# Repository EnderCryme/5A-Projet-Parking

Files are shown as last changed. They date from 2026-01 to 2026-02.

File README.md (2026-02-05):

# 🏆 PSM - Modular Smart Parking System
### *Winner of "Most Technical Project" - Digital Majors Competition 2025*




<div align="center">
  PSM Prototype
  <p><em>Our award-winning prototype at the competition</em></p>
</div>

---
## 🏅 **Award & Recognition**
We are proud to announce that **PSM won the "Most Technical Project" award** at Digital Majors Competition 2025 !
Our solution stood out for its:
* ✅ **Distributed IoT architecture** combining FPGA, STM32, and BeagleY-AI
* ✅ **Custom RISC-V SoC** implemented on FPGA
* ✅ **Real-time ANPR system** with OpenCV + Tesseract
* ✅ **Industrial-grade implementation** with Zephyr RTOS

<div align="center">
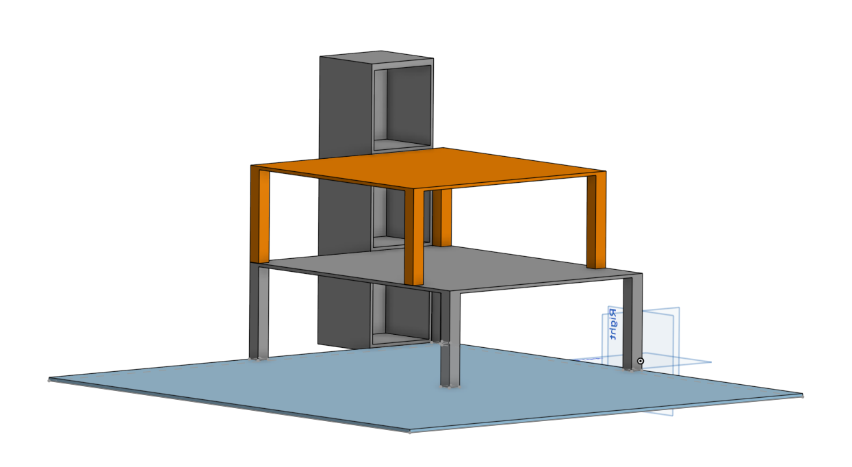
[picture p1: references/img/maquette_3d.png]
3D Model
  
  <p><em>3D model of our mechanical design</em></p>
</div>

---

## 🌍 **Choose Your Language**
For full project details, please select your preferred language:

🇫🇷 **[Version Française (README_fr.md)](README_FR.md)**
🇬🇧 **[English Version (README_en.md)](README_EN.md)**

---

## 🔧 **Quick Overview**
**Key Features:**
- **AI-powered ANPR** (Automatic Number Plate Recognition)
- **Distributed MQTT network** with BeagleY-AI as central broker
- **Custom RISC-V SoC** on FPGA for motor control
- **Zephyr RTOS** for real-time RFID processing
- **Modular design** with 3D-printed mechanical components

**Tech Stack:**





---

## 👥 **Project Team**
* **FALDA Andy**
* **CAUQUIL Vincent**
* **ES-SRIEJ Youness**
* **CLERVILLE Annabelle**

---

## 📸 **Gallery**
<div align="center">
  <table>
    <tr>
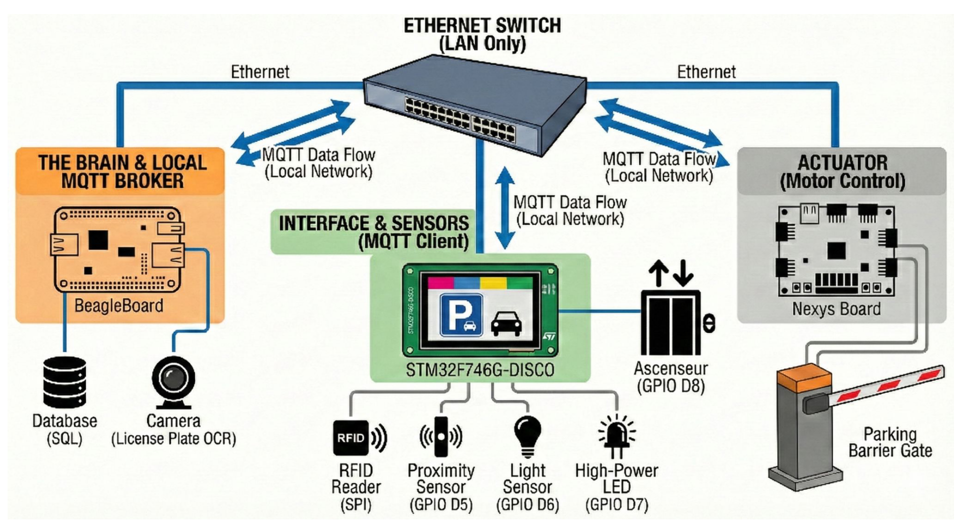
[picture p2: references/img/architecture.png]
      <td></td>
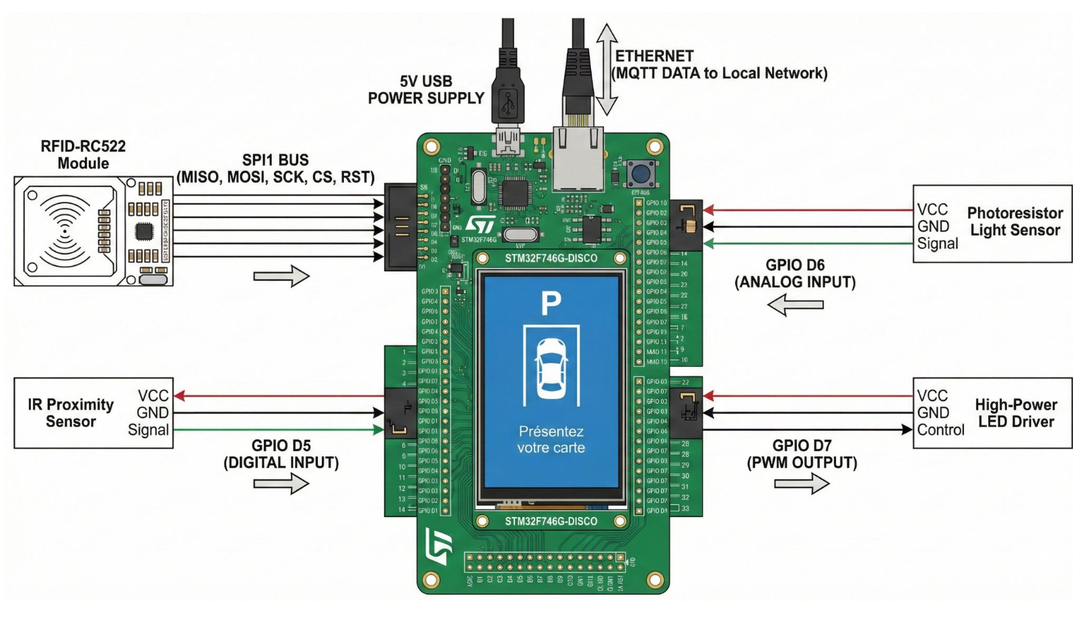
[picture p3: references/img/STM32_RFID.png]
      <td></td>
    </tr>
    <tr>
      <td align="center"><em>Complete system</em></td>
      <td align="center"><em>RFID entry module</em></td>
    </tr>
  </table>
</div>

> *Note: For more images and technical diagrams, please refer to the full documentation in [README_fr.md](README_FR.md) or [README_en.md](README_EN.md).*

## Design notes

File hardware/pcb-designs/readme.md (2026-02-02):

# **PCB Design**





Ce répertoire contient l’ensemble des **cartes électroniques (PCB)** développées pour le système.  
Tous les schémas et routages ont été réalisés sous **KiCad 7**, en respectant les contraintes des signaux rapides (MIPI, USB), la sécurité électrique, ainsi que la compatibilité avec **USB‑C Power Delivery**.

---
# 📁 Structure du Répertoire

```
/pcb-designs
   ├── adaptateur-24pin/            # Convertisseur Mipi to CSI
   │   ├── GERBER-Adaptateur/
   │   ├── Adapat_24pin_22pin.kicad_pcb
   │   ├── Adapat_24pin_22pin.kicad_sch
   │   └── Adapat_24pin_22pin.rar
   ├── bms/                            # Layout et ressources de design du BMS
   │   ├── calculations/               # Justifications techniques
   │   │   ├── load_estimation.csv
   │   │   └── pack_4S3P_energy.csv
   │   ├── designs/                    # Sources du projet KiCad
   │   │   ├── BMS.csv                 # BOM compatible JLCPCB
   │   │   ├── BMS_schem.kicad_prl     # Fichier projet KiCad du BMS
   │   │   ├── BMS_schem.kicad_sch     # Schématique complet
   │   │   ├── BMS_pcb.kicad_pcb       # Routage (4 couches, impédance contrôlée)
   │   │   ├── BMS.pdf                 # Feuilles circuits au format pdf ⚠ Ne pas imprimer comme tel,
   │   │   └── ....                      il y'a des feuilles inutiles utilisés pour simplifié le circuitage
   │   ├── references/                 # Datasheets composants (STM32, STUSB...)
   │   ├── test-EVM/                   # Tests sur carte d'évaluation (BQ40Z50)
   │   ├── BMS_schem.png
   │   ├── bilan-puissance-max.png
   │   ├── readme.md
   │   └── .... ⚠ le firmware RP2350 est trouvable au : /software/sw-fw-BMS
   ├── common-libs/                    # Lib cstm avec les empreintes steps et schémas utilisés
   └── detection-lumiere/              # Détection d'intensité lumineuse
       ├── Gerber/
       ├── Lumiere.kicad_pcb
       ├── Lumiere.kicad_sch
       └── readme.md         
```

---

## **1. BMS – Battery Management System**

Dans le cadre du projet, il m’a été confié de gérer **toute la partie puissance**, ainsi que d’anticiper différents **scénarios hors‑réseau**, impliquant l’utilisation d’un système de batteries rechargeable.

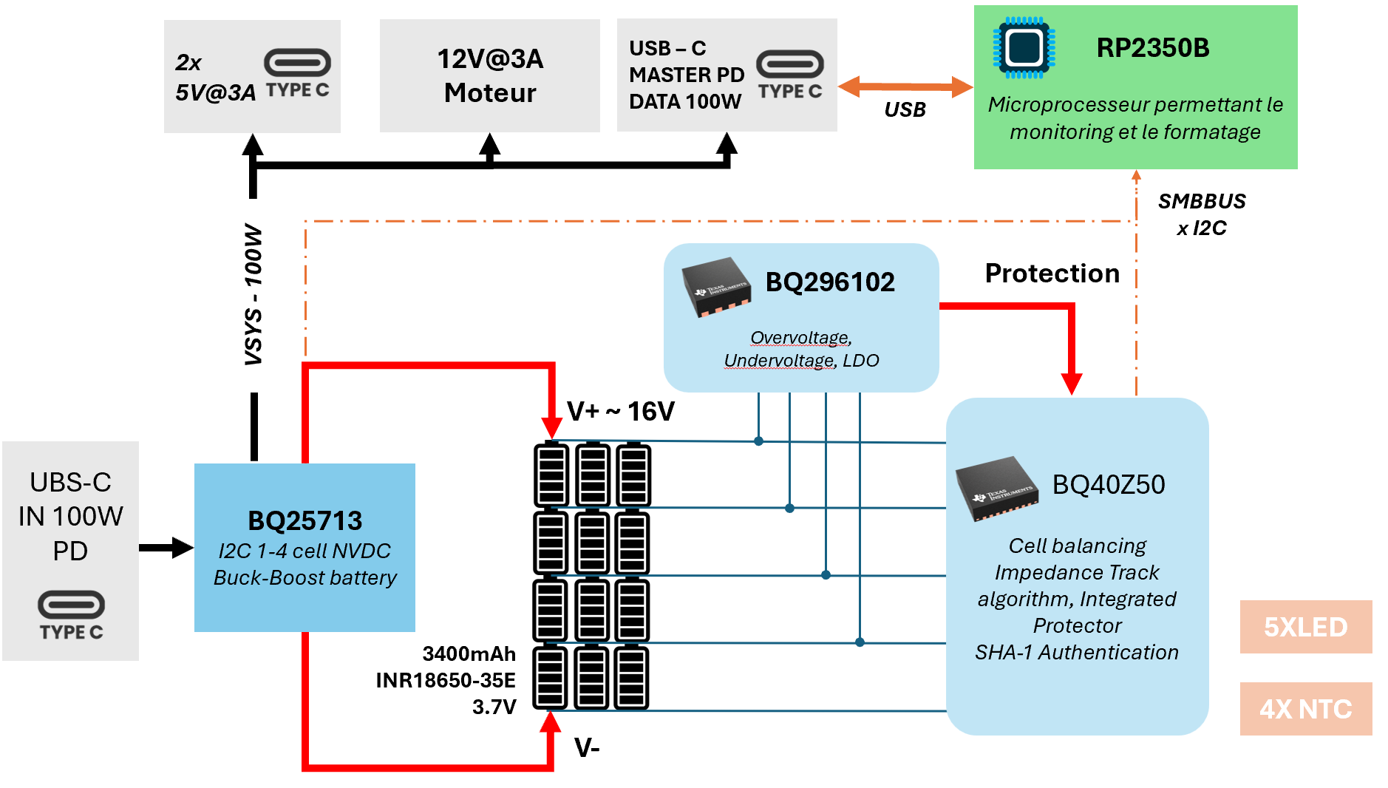
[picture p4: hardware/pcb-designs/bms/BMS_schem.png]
BMS


L’alimentation principale repose sur un port **USB Type‑C avec Power Delivery (PD)** pour plusieurs raisons :

### **Pourquoi l’USB Type‑C PD ?**
- **Standard universel** : compatible avec la majorité des chargeurs actuels.  
- **Négociation automatique de puissance (PD)** :  
  Le système consomme précisément ce dont il a besoin, et limite ce qu’il fournit.  
- **Flexibilité du système** :  
  Permet d’adapter le nombre de cellules, l’autonomie et le chargeur utilisé.  
  Plage de puissance supportée : **5 W → 100 W**.

Le système sélectionne automatiquement la tension adéquate parmi les différents PDO du chargeur (5V / 9V / 12V / 15V / 20V).  
Cela le rend particulièrement robuste pour des scénarios variés : installations autonomes, postes IoT isolés, alimentation redondante, robotique mobile, etc.

---

## **2. Capteur de lumière**

L’intégration d’un **capteur de luminosité** permet de détecter un niveau d’éclairage insuffisant pour activer automatiquement l’éclairage du site.

### Objectif
- Allumer les LED dès qu’il fait suffisamment sombre (ex. crépuscule).  
- Éviter tout éclairage inutile en pleine journée.

### Couplage avec un capteur de présence
Associé à un détecteur de mouvement, ce capteur permet :
- Une **réduction de la consommation électrique**.  
- Une **diminution de la pollution lumineuse** pour le voisinage.  
- Une **optimisation énergétique** en n’éclairant que lorsque cela est nécessaire.

Cette approche rend le système plus intelligent, écoresponsable et parfaitement adapté à une installation extérieure automatique.

---

## **3. Adaptateur MIPI/CSI 24‑pin vers 22‑pin**

Cette carte d’adaptation permet de rendre compatible une caméra industrielle **Sony [IMX415](https://www.aliexpress.com/p/tesla-landing/index.html?productId=1005006459824998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)** (connecteur **24‑pins**) avec nos plateformes **BeagleBone AI‑64 / BeagleBone Y‑AI**, qui utilisent un connecteur **22‑pins CSI‑2**.

### Pourquoi un adaptateur ?
- Les caméras industrielles IMX utilisent fréquemment un **pinout 24‑pins propriétaire**.  
- Les cartes BBY reposent sur un **pinout 22‑pins CSI‑2 standardisé**.  
- Une réaffectation correcte des signaux MIPI est nécessaire :  
  - Clock lanes  
  - Data lanes  
  - Alimentation  
  - I²C / Reset / Standby  

### Rôle de la carte
- Conversion **mécanique** entre les connecteurs 24→22.  
- Conversion **électrique passive**, sans électronique active.  
- **Maintien de l’intégrité des signaux haute‑vitesse** grâce à :  
  - une impédance contrôlée,  
  - des longueurs adaptées,  
  - un routage équilibré des paires différentielles.

Cette carte garantit une compatibilité propre et robuste avec notre matériel, tout en conservant les performances du capteur IMX415.

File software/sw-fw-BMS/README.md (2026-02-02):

# Firmware/Software BMS Intelligent 

Cette section contient le firmware de contrôle pour le sous-ensemble BMS. Développé en **MicroPython**, ce logiciel transforme le RP2350 en une unité de gestion intelligente capable de dialoguer avec le contrôleur **BQ40Z50** via le protocole **SMBus**.

Le code assure la lecture des paramètres critiques de la batterie, la gestion de l'affichage local et le pilotage des sécurités de l'étage de puissance.

## 🛠️ Architecture du Firmware/Software

### 1. Communication SMBus / I2C

Le firmware exploite le bus I2C (GPIO 8 & 9) à une fréquence de 400kHz pour interroger les registres standards du BQ40Z50:

* **V Tension (`0x09`)** : Acquisition en millivolts.
* **A Courant (`0x0A`)** : Lecture signée gérant la charge (+) et la décharge (-).
* **% État de Charge (`0x0D`)** : Récupération directe du SoC (State of Charge).
* **T Température (`0x08`)** : Conversion de Kelvin (0.1°K) vers Celsius.

### 2. Logique de Contrôle & Sécurité

Le firmware agit comme le superviseur du système via des signaux de contrôle dédiés :

* **Signal CTRL (`GPIO 44`)** : Pilotage de la grille du MOSFET DMP3035 pour l'activation des sorties USB-C 5V@3A.
* **Monitoring ADC (`GPIO 43`)** : Surveillance de la tension VBUS via un pont diviseur de tension (47k/33k) pour valider la régulation.

## 🚀 Installation & Autorun

### 1. Préparation du RP2350

* Téléchargez le firmware MicroPython `.uf2` pour **Pico 2** sur [micropython.org](https://micropython.org/download/RPI_PICO2/).
* Maintenez le bouton **SW2** (USB_BOOT) enfoncé et branchez le module en USB.
* Copiez le fichier `.uf2` dans le lecteur `RPI-RP3`.

### 2. Déploiement du Code

Utilisez **Thonny IDE** pour téléverser les fichiers à la racine du microcontrôleur :
*  `ssd1306.py` : Pilote basse couche pour l'écran OLED.
* **`main.py`** : Script principal contenant la boucle de monitoring (se lance automatiquement à l'allumage).

## 📡 Interface Utilisateur (OLED)

L'affichage est rafraîchi toutes les secondes et présente un dashboard complet:

* **Ligne 1** : Tension (V) et Température (°C).
* **Ligne 2** : Courant de charge/décharge (A).
* **Ligne 3** : Barre de progression graphique du niveau de batterie.

## 📂 Structure des fichiers Software
```text
sw-fw-BMS/
 ├── BMS_schem.png    # Schéma récapitulatif de l'architecture du BMS
 ├── README.md
 ├── main.py          # Logique métier et boucle principale.
 └── ssd1306.py       # Bibliothèque d'affichage I2C.
```

---

### 📑 Table des Commandes I2C (SMBus/Relier aux registres visibles sur le BQstudio)

| Commande | Registre (Hex) | Unité | Description |
| --- | --- | --- | --- |
| **Temperature** | `0x08` | 0.1°K | Température interne du pack (convertie en °C dans le code).
| **Voltage** | `0x09` | mV | Tension totale aux bornes du pack batterie.
| **Current** | `0x0A` | mA | Courant instantané (positif = charge, négatif = décharge).
| **RelativeSoC** | `0x0D` | % | État de charge restant par rapport à la capacité actuelle.

---

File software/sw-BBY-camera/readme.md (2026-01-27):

# Système de Gestion Centralisé (BeagleBone Node)







## 📖 Description du Projet

Ce dépôt contient le "cerveau" du système de parking intelligent. Exécuté sur une **BeagleBone Black / BeagleY-AI**, ce nœud centralise la logique métier, la gestion de la base de données et le traitement d'images.

Il agit comme une passerelle (Gateway) qui coordonne les périphériques via MQTT (comme le nœud STM32), offre une interface Web d'administration et effectue la reconnaissance optique de caractères (ALPR) en temps réel.

### Fonctionnalités Clés

* **Reconnaissance LAPI (ALPR) :** Détection et lecture automatique des plaques d'immatriculation via **OpenCV** (Haar Cascades) et **Tesseract OCR**.
* **Serveur Web (Flask) :** Dashboard complet pour l'administration (IT) et les clients (User) avec streaming vidéo MJPEG.
* **Base de Données (SQLite) :** Gestion persistance des utilisateurs, historique des entrées/sorties et droits d'accès.
* **Logique de Contrôle :** Moteur de décision fusionnant les données RFID (MQTT) et Vidéo pour piloter les barrières.
* **Affichage Local (SPI) :** Pilotage d'une matrice LED/LCD pour les messages d'accueil et la météo locale.
* **Mode Hybride :** Capacité de fonctionner en mode "Simulation" sur PC (Windows) ou en mode "Matériel Réel" sur Linux (détection automatique).

## 🛠 Architecture Matérielle

* **SBC :** BeagleBone Black Wireless / BeagleY-AI (Debian Linux)
* **Vision :** Webcams USB (Entrée/Sortie)
* **Affichage :** Matrice LED (MAX7219) via SPI
* **Capteurs :** BME680 (Température/Pression/Humidité)

### Pinout & Connexions

| Périphérique | Pin BeagleBone | Bus | Description |
| :--- | :--- | :--- | :--- |
| **LCD / Matrice** | `P9_17` (CS0) | SPI0 | Affichage messages défilants |
| **Capteur BME680** | `P9_28` (CS1) | SPI0 | Télémétrie environnementale |
| **Caméra Entrée** | USB Host | USB | Flux Vidéo 1 (`/vid_in`) |
| **Caméra Sortie** | USB Host | USB | Flux Vidéo 2 (`/vid_out`) |

## 📡 API MQTT

Le serveur agit comme le maître logique sur le réseau local.

| Topic | Direction | Payload | Description |
| :--- | :--- | :--- | :--- |
| `RFID/ID` | Sub (In) | `[UID]` | Réception d'un badge scanné par le STM32. |
| `RFID/CMD` | Pub (Out) | `UNLOCK_READY` | Indique au STM32 que le badge est valide. |
| `RFID/CMD` | Pub (Out) | `DENY` | Indique au STM32 que l'accès est refusé. |
| `parking/barrier_x/state` | Pub (Out) | `OPEN` / `CLOSE` | Ordre d'ouverture des barrières physiques. |
| `RFID/ADD` | Sub (In) | `[UID]` | Demande d'ajout rapide d'un badge (Admin). |

## ☁️ Ouverture : Architecture Cloud & Edge Computing

Actuellement, le projet fonctionne en mode "autonome" (le serveur Web et l'IA tournent sur la même machine). Pour un déploiement réel à grande échelle (ex: via Render ou AWS), l'architecture évoluerait vers un modèle **IoT Edge** :

1. **Sur site (Edge Node)** : Un script python léger (`local_bridge.py`) tourne sur la BeagleBone. Il gère :
    * L'acquisition vidéo et l'OCR (Traitement local pour rapidité).
    * Le pilotage physique (GPIO) des barrières et écrans LCD.
    * La communication sécurisée via **MQTT (TLS)** vers le Cloud.

2. **Sur le Cloud (Server Node)** : L'application Flask (`main_v08d.py`) est hébergée sur un serveur distant. Elle gère :
    * La base de données centralisée.
    * L'interface administrateur accessible de partout.
    * La validation des entrées : elle reçoit la plaque via MQTT, vérifie les droits, et renvoie l'ordre d'ouverture à la BeagleBone.

3. **Flux Vidéo** : Plutôt que de streamer de la vidéo lourde, le nœud local envoie des **Snapshots (images instantanées)** en base64 via MQTT ou via un tunnel WebRTC lors des événements importants (détection, effraction), optimisant ainsi la bande passante 4G/5G des parkings isolés.

## ⚙️ Installation & Démarrage

Le projet nécessite Python 3.9+ et les drivers système.

### Pré-requis

```bash
# Installation des dépendances système (Debian/Ubuntu)
sudo apt update
sudo apt install python3-opencv tesseract-ocr libopenjp2-7

# Installation des bibliothèques Python
pip install -r requirements.txt

```

### Lancement

Le système détecte automatiquement s'il tourne sur un PC (Simulation) ou sur la BeagleBone (SPI activé).

```bash
# Lancement du serveur principal
python3 main_v08d.py

```

*L'interface web est accessible sur `http://<IP_BEAGLEBONE>:5000*`

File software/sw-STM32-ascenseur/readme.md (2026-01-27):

# Système de Contrôle d'Ascenseur Intelligent (STM32 Node)






## 📖 Description du Projet

Ce dépôt contient le firmware d'un système de contrôle d'ascenseur de précision. Le projet implémente un pilotage avancé de moteur pas-à-pas associé à un asservissement par capteur de distance laser pour garantir un positionnement exact aux différents niveaux.

Le système intègre une gestion complète de la sécurité (fin de course, arrêts d'urgence) et une rampe d'accélération logicielle pour assurer des mouvements fluides et prévenir l'usure mécanique.

### 🚀 Fonctionnalités Clés

* **Pilotage TMC5160 (SPI) :** Gestion avancée du driver moteur avec surveillance d'état et résilience automatique en cas de défaut.
* **Recalibrage Automatique :** Séquence d'initialisation au démarrage pour définir le point zéro via capteur de fin de course.
* **Positionnement Laser (ToF) :** Utilisation du capteur VL53L0X pour le recalage en temps réel et la correction de dérive.
* **Rampe d'Accélération :** Algorithme de vitesse dynamique pour limiter les secousses lors des phases de départ et d'arrêt.
* **Gestion Multi-étages :** Support natif de 3 niveaux configurables avec système de mémorisation des appels en attente.
* **Sécurité Active :** Surveillance du bouton d'arrêt d'urgence et détection de collision/sol lors de la descente.

## 🛠 Architecture Matérielle

* **MCU :** STM32F746NG (Arm Cortex-M7)
* **Board :** STM32F746G-DISCO
* **Driver Moteur :** TMC5160 SilentStepStick
* **Capteur :** VL53L0X (Laser Distance)

### Pinout & Connexions (Overlay)

| Périphérique | Pin STM32 | Type | Description |
| :--- | :--- | :--- | :--- |
| **Moteur STEP** | `PA15` | GPIO Out | Signal de pas |
| **Moteur DIR** | `PI2` | GPIO Out | Direction du mouvement |
| **Moteur ENABLE**| `PI3` | GPIO Out | Activation driver (Actif Low) |
| **TMC CS** | `PA8` | GPIO Out | Chip Select SPI |
| **Fin de Course** | `PH6` | GPIO In | Capteur Point Zéro (D6) |
| **Appel Étage 0**| `PG6` | GPIO In | Bouton Rez-de-chaussée (D2) |
| **Appel Étage 1**| `PG7` | GPIO In | Bouton Niveau 1 (D4) |
| **Appel Étage 2**| `PI0` | GPIO In | Bouton Niveau 2 (D5) |

## ⚙️ Paramètres de Calibration (main.c)

| Paramètre | Valeur | Unité |
| :--- | :--- | :--- |
| **Hauteur Étage 0** | 0 | mm |
| **Hauteur Étage 1** | 170 | mm |
| **Hauteur Étage 2** | 336 | mm |
| **Résolution** | 350 | pas / mm |
| **Tolérance** | 10 | mm |

## 📡 Configuration & Build

Le projet est basé sur **Zephyr RTOS**.

### Pré-requis
* Zephyr SDK installé.
* West build tool.

### Commandes

```bash
# Compiler le projet pour la STM32F746G-DISCO
west build -p -b stm32f746g_disco

# Flasher la carte
west flashn --runner openocd

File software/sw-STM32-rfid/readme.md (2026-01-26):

# Système d'Accès Parking Automatisé (STM32 Node)






## 📖 Description du Projet

Ce dépôt contient le firmware du sous-système d'interface et de gestion d'accès pour un parking automatisé. Le système repose sur une architecture IoT distribuée où ce module STM32 agit comme un **nœud de périphérie (Edge Node)** intelligent.

Il assure l'interface homme-machine, l'acquisition des données environnementales en temps réel et la sécurité physique de l'accès (Anti-Tailgating) avant de communiquer avec le serveur central (BeagleBoard) via MQTT sur Ethernet.

### 🚀 Fonctionnalités Clés

* **Identification RFID (SPI) :** Lecture de badges Mifare via module RC522.
* **Interface Tactile (LVGL) :** IHM interactive avec rotation logicielle (180°) pour adaptation mécanique.
* **Gestion Éclairage (GPIO) :** Pilotage automatique via capteur de luminosité et relais de puissance.
* **Sécurité Active :** Algorithme "Anti-Tailgating" pour prévenir la fraude au passage barrière.
* **Mode Maintenance :** Badge Administrateur (`UID: AA63F605`) pour gestion locale (Ajout/Suppr clients).
* **Communication IoT :** Client MQTT asynchrone pour la télémétrie et le contrôle distant.

## 🛠 Architecture Matérielle

* **MCU :** STM32F746NG (Arm Cortex-M7)
* **Board :** STM32F746G-DISCO
* **Affichage :** LCD 4.3" (480x272) capacitif
* **Réseau :** Ethernet (RJ45)

### Pinout & Connexions (Overlay)

| Périphérique | Pin STM32 | Type | Description |
| :--- | :--- | :--- | :--- |
| **RFID RC522** | SPI2 Bus | SPI | Lecteur de badges 13.56MHz |
| **RFID CS** | `PA8` | GPIO Out | Chip Select RFID |
| **Capteur Prox** | `PI0` | GPIO In | Détection présence véhicule (Actif High) |
| **Capteur Lum** | `PH6` | GPIO In | Photorésistance (Actif Low) |
| **Relais LED** | `PI3` | GPIO Out | Commande éclairage puissance 12V |
| **Backlight** | `PK3` | GPIO Out | Rétroéclairage LCD (Eco-mode) |

## 📡 API MQTT

Le système communique sur le réseau local configuré tel que :
Broker @ 192.168.78.2, STM32 @ 192.168.78.3

| Topic | Direction | Payload | Description |
| :--- | :--- | :--- | :--- |
| `RFID/ID` | Pub (Out) | `[UID]` | Envoi de l'UID scanné au serveur. |
| `RFID/PRESENCE` | Pub (Out) | `0` / `1` | État du capteur de présence véhicule. |
| `RFID/CMD` | Sub (In) | `UNLOCK`/`DENY` | Réponse du serveur (Accès autorisé/refusé). |
| `parking/barrier_0/state` | Pub/Sub | `OPEN`/`CLOSE` | Commande directe de la barrière physique. |

## ⚙️ Configuration & Build

Le projet est basé sur **Zephyr OS**.

### Pré-requis
* Zephyr SDK installé.
* West build tool.

### Commandes de Build

```bash
# Compilation propre pour la cible disco
west build -p always -b stm32f746g_disco

# Flashage sur la carte
west flash

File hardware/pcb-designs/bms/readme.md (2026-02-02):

# **Battery Management System (BMS)**






Ce dossier contient l’ensemble des fichiers de conception de la **carte BMS** (Battery Management System).  
L'objectif est de fournir une alimentation autonome, robuste et sécurisée pour le système embarqué hétérogène (BeagleY-AI, STM32, FPGA Nexys et moteurs).

Tout est conçu sous **KiCad 7**, avec une attention particulière aux contraintes haute tension (16.8 V), aux courants forts et à la sécurité thermique.

---

# 📁 Structure du Répertoire

```
bms/                               # Layout et ressources de design du BMS
   ├── calculations/               # Justifications techniques
   │   ├── load_estimation.csv
   │   └── pack_4S3P_energy.csv
   ├── designs/                    # Sources du projet KiCad
   │   ├── BMS.csv                 # BOM compatible JLCPCB
   │   ├── BMS_schem.kicad_prl     # Fichier projet KiCad du BMS
   │   ├── BMS_schem.kicad_sch     # Schématique complet
   │   ├── BMS_pcb.kicad_pcb       # Routage (4 couches, impédance contrôlée)
   │   ├── BMS.pdf                 # Feuilles circuits au format pdf ⚠ Ne pas imprimer comme tel,
   │   └── ....                      il y'a des feuilles inutiles utilisés pour simplifié le circuitage
   ├── references/                 # Datasheets composants (STM32, STUSB...)
   ├── test-EVM/                   # Tests sur carte d'évaluation (BQ40Z50)
   ├── BMS_schem.png
   ├── bilan-puissance-max.png
   ├── readme.md
   └── .... ⚠ le firmware RP2350 est trouvable au : /software/sw-fw-BMS
```

---

## **1. Architecture Système**

Le BMS ne se contente pas de charger des batteries ; il gère toute la distribution de puissance. L'architecture repose sur un trio de composants **Texas Instruments** pour la partie puissance/sécurité, et un **RP2350** pour l'intelligence applicative.

Architecture Simplifiée

### **Le Trio de Puissance (TI)**
La mesure critique et la sécurité sont **100 % hardware**, découplées du microcontrôleur pour une fiabilité maximale.

| Composant | Fonction | Pourquoi ce choix ? |
|:---|:---|:---|
| **BQ25713** | Chargeur Buck-Boost NVDC | Gère l'USB-C PD (5V→20V) et charge le pack quelle que soit l'entrée. |
| **BQ40Z50** | Fuel Gauge & Protection | Algorithme *Impedance Track™*, balancing cellules, protections primaires. |
| **BQ296102** | Protection Secondaire | Fusible électronique ultime (OVP/UVP) totalement indépendant. |

> **Note importante :** La configuration bas niveau du BQ40Z50 (profils batterie `.gg`, calibration) nécessite l'outil **TI EV2400**. Sans cela, la puce reste en mode défaut.

---

## **2. Dimensionnement du Battery Pack – 4S3P**

Le choix des cellules s'est porté sur des **Samsung INR18650‑35E** (3.7 V, 3400 mAh), assemblées en une configuration **4S3P**.

### **Caractéristiques du Pack**
*   **Capacité :** $3 \times 3.4\,Ah = 10.2\,Ah$
*   **Énergie :** $14.8\,V \times 10.2\,Ah = 151\,Wh$
*   **Tension Nominale :** 14.8 V
*   **Tension Max (Charge) :** 16.8 V
*   **Tension Min (Sécurité) :** 12.8 V

### **2.1. Justification du 4S et Évolution vers 20 V**

**L'approche initiale :**
Le pack 4S a été dimensionné initialement pour s'aligner sur une tension système globale de **12 V à 15 V**, idéale pour limiter les pertes de conversion vers les rails logiques (5V) et périphériques standards (12V).

**Le constat mécanique :**
Lors des tests d'intégration, nous avons remarqué que le moteur pas-à-pas de l'ascenseur (Stepper) manquait de fluidité sous 15 V (à-coups à haute vitesse, couple instable). Les essais ont montré un comportement mécanique optimal et parfaitement fluide sous **18–20 V**.

**La solution architecturale (Buck-Boost) :**
Ce changement de prérequis n'a pas impacté la batterie. L'architecture de puissance de la carte BMS intègre une topologie flexible :
*   **Buck (Abaisseur) :** Pour générer les rails 12 V, 5 V et 3.3 V avec un haut rendement.
*   **Boost (Élévateur) :** Pour rehausser la tension batterie (12.8V - 16.8V) vers le rail **20 V** nécessaire aux moteurs.

> Cette flexibilité permet de conserver un pack compact (4S) et compatible USB-C PD, tout en fournissant la haute tension requise par la mécanique.
---

## **3. Entrée USB-C Power Delivery**

L'alimentation se fait via un port USB-C compatible **Power Delivery (PD) jusqu'à 100W**.

*   **Universel :** Fonctionne avec n'importe quel chargeur de laptop ou téléphone (5V, 9V, 12V, 15V, 20V).
*   **Négociation Automatique :** Le BQ25713 négocie la tension max disponible et adapte son étage Buck-Boost pour charger le pack 4S (qui demande ~16.8V).
*   **Rendement :** L'architecture NVDC (Narrow Voltage DC) optimise l'efficacité et permet au système de démarrer même si la batterie est vide.

---

## **4. Intelligence & Supervision : RP2350 vs STM32**

Pour l'interface utilisateur (OLED), la télémétrie et la supervision non-critique, nous avons choisi le **RP2350**.

### **Pourquoi pas un STM32 standard (ex: F4/G4) ?**
Nous avons appliqué un **Indice de Performance Normalisé (IPN)** pour objectiver le choix :

$$ IPN = \frac{\text{Cœurs} \times \text{Fréquence} \times \text{GPIO}}{\text{Prix (€)}} $$

*   **STM32 (G4 typique) :** 1 cœur, 170MHz, cher (~4.50€) $\rightarrow$ **IPN ≈ 444**
*   **RP2350 :** 2 cœurs, 150MHz, beaucoup de GPIO, pas cher (~1.20€) $\rightarrow$ **IPN ≈ 8500**

Le RP2350 est **~19x plus rentable** pour ce rôle de supervision. Il récupère les infos du BQ40Z50 via SMBus et gère l'affichage, laissant la sécurité pure aux puces TI.

---

## **5. Bilan de Puissance & Autonomie**

Le dimensionnement énergétique du BMS est dicté par une architecture matérielle complexe et hétérogène. L'image ci-dessous résume l'ensemble des composants actifs dans le scénario de consommation maximale ("Max du Max").

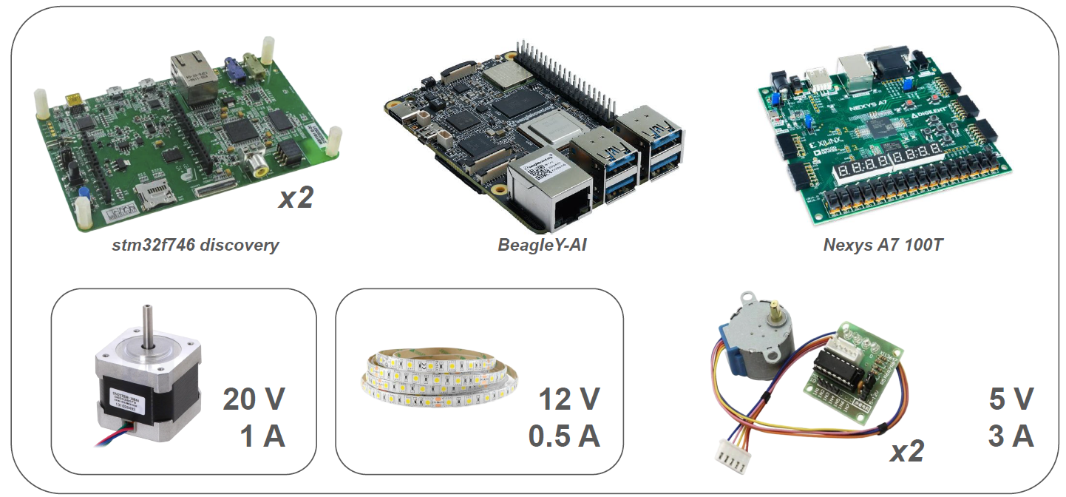
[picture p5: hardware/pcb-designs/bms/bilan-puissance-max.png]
Hardware Ecosystem

*Vue d'ensemble des charges connectées : FPGA, Processeurs AI, Microcontrôleurs et Actionneurs.*

### **5.1. Détail de la consommation (Worst Case)**
Le tableau suivant quantifie la puissance requise lorsque tous les éléments ci-dessus sont sollicités simultanément (Calcul intensif + Moteurs en couple de maintien ou mouvement).

| Charge | Tension | Courant Max | Puissance |
|:---|:---|:---|:---|
| **BeagleY‑AI** | 5 V | 3 A | **15 W** |
| **Nexys A7‑100T (FPGA)** | 5 V | 3 A | **15 W** |
| **Moteurs NEMA (via Boost)** | 20 V | 1 A | **20 W** |
| **Strip LED** | 12 V | 0.5 A | **6 W** |
| **2× STM32F746** | 5 V | 1 A | **5 W** |
| **2× Mini‑Stepper** | 5 V | 0.8 A | **4 W** |
| **TOTAL (Nominal)** | | | **65 W** |

> **Dimensionnement Sécuritaire :** Avec une marge de sécurité de **20 %** (pics de courant moteurs et rendement des convertisseurs), le système est dimensionné pour fournir jusqu'à **78 W** en pointe.

### **5.2. Scénarios d'autonomie**
Le pack batterie **4S3P (151 Wh)** offre une grande flexibilité d'usage. Nous avons mesuré une consommation plancher (Idle) de **18 W** lorsque tout le système est alimenté mais en attente d'instruction.

| Scénario | Condition | Puissance | Autonomie estimée |
|:---|:---|:---|:---|
| **Intensif (Marge)** | Full Load + 20 % (Stress test) | 78 W | **≈ 1h 55** |
| **Intensif (Nominal)** | Robot en mouvement + IA active | 65 W | **≈ 2h 20** |
| **Mixte** | Usage standard moyen | 40 W | **≈ 3h 45** |
| **Repos (Idle)** | Tout connecté, moteurs à l'arrêt | **18 W** | **≈ 8h 20** |

> **Conclusion :** L'architecture garantit près de **2 heures** d'autonomie en régime maximal hors réseau (calcul IA + déplacement continu) et assure une journée complète (**>8h**) en veille active, permettant la continuité du service de parking même en cas de coupure du réseau électrique, ou durant une maintenant.

### **5.3. Extension d'Autonomie (Solaire / Éolien 50 W)**

Pour répondre aux exigences d'un fonctionnement en extérieur ou en site isolé, l'architecture d'alimentation permet l'intégration de sources d'énergie renouvelables. Le dimensionnement cible un apport de **50 W** (ex: panneau solaire monocristallin standard ou petite éolienne).

Cet apport transforme le BMS en système hybride, capable de recharge en cours de fonctionnement (*Pass-through Charging*).

#### **Impact du scénario 50 W sur le bilan énergétique**
L'injection de 50 W permet de couvrir intégralement la consommation au repos et mixte, et de compenser drastiquement la consommation en pleine charge.

| Mode de fonctionnement | Consommation ($P_{load}$) | Apport Solaire ($P_{in}$) | Bilan Net sur Batterie ($P_{net}$) | Conséquence |
|:---|:---:|:---:|:---:|:---|
| **Repos (Idle)** | 18 W | + 50 W | **+ 32 W (Recharge)** | **Autonomie Infinie** + Recharge rapide du pack |
| **Mixte (Standard)** | 40 W | + 50 W | **+ 10 W (Recharge)** | **Autonomie Infinie** + Maintien de charge |
| **Intensif (Nominal)** | 65 W | + 50 W | **- 15 W (Décharge)** | Décharge très lente. Autonomie étendue à **≈ 10h** (vs 2h20) |

#### **Méthodologie de calcul du gain**
L'autonomie étendue ($T_{ext}$) est calculée en fonction du **Bilan Net** de puissance puisée sur la batterie. Avec un robot consommant **65 W** et un apport de **50 W**, le différentiel est de :

$$P_{net} = 65~W - 50~W = \mathbf{15~W}$$

L'autonomie théorique devient alors :
$$T_{ext} = \cfrac{E_{batt}}{P_{net}} = \cfrac{151~Wh}{15~W} \approx \mathbf{10,06~Heures}$$

#### **Implémentation technique simplifiée (USB-C PD)**
L'intégration de cette source d'énergie est rendue native par l'usage du port **USB-C** bidirectionnel. Il n'est pas nécessaire de modifier le hardware du BMS, ni d'ajouter des convertisseurs MPPT externes complexes.

1.  **Côté Source (Solaire/Éolien) :** Il suffit d'équiper la sortie du panneau d'un **contrôleur USB-PD standard**. Celui-ci négocie automatiquement la tension optimale (ex: 20 V) dès la connexion.
2.  **Gestion Intelligente (RP2350 & BQ25713) :**
    *   Le **RP2350** détecte la connexion et communique avec le BQ25713 via I2C.
    *   Il identifie le profil de puissance disponible (PDO) annoncé par la source.
    *   Il adapte dynamiquement la limite de courant d'entrée ($I_{in\_{lim}}$) pour maximiser la puissance extraite sans effondrer la tension du panneau, garantissant une stabilité parfaite du système hybride.

> **Conclusion "Smart Grid" :** L'apport solaire ne se contente pas de recharger la batterie ; il soulage le pack de **77 %** de l'effort en charge nominale. Cela multiplie l'autonomie opérationnelle par un facteur **4**, permettant de tenir une journée de travail intense sans jamais se brancher au secteur.

---
## **6. Sécurité (Safety Layers)**

La sécurité est implémentée en couches successives ("Oignon de sécurité") :

1.  **Gestionnaire (Gauge) :** Le BQ40Z50 surveille en permanence T°, V, I. Il coupe les MOSFETs en cas d'anomalie.
2.  **Protection Secondaire :** Le BQ296102 surveille uniquement les surtensions (OVP) et sous-tensions (UVP). S'il déclenche, il grille un fusible chimique commandé (CIP) pour isoler physiquement le pack.
3.  **Thermique :** 4 sondes NTC sont collées directement sur les cellules pour détecter tout emballement thermique.
4.  **Physique :** Fusibles sur les I/O et diodes TVS sur les ports externes (USB-C, borniers).

---

## **7. Interfaces d'Entrées/Sorties & Extensions (I/O)**

Le BMS a été conçu pour être plus qu'une simple alimentation : c'est un périphérique intelligent et interactif. L'architecture autour du **RP2350** exploite ses nombreuses broches pour offrir des fonctions de diagnostic local, de pilotage fin des sorties et de mise à jour simplifiée.

### **7.1. Port Master & Programmation (Lien BeagleBone)**
Une interface de communication privilégiée relie le BMS au cerveau du robot (BeagleBone AI-64). Ce port remplit un double rôle crucial via les lignes de données (D+/D-) :
*   **Télémétrie & Contrôle :** En fonctionnement normal, le BeagleBone récupère les statistiques (SOC, puissance instantanée) via une liaison série/USB.
*   **Mise à jour Firmware (Mode Prog) :** Le BMS peut basculer en mode "Bootloader", permettant au BeagleBone de reflasher le RP2350 à la volée. Cela garantit un système évolutif, capable de recevoir des correctifs ou de nouvelles stratégies de charge sans démontage matériel.

### **7.2. Interface Homme-Machine (IHM) Locale**
Pour faciliter le diagnostic sur le terrain (sans avoir besoin de connecter un PC), le BMS intègre sa propre interface utilisateur :
*   **Écran OLED (I2C) :** Affiche en temps réel l'état de santé du pack (SOH), le pourcentage de batterie, la tension globale et le courant consommé/chargé.
*   **Boutons de Navigation :** Une série de boutons poussoirs permet de naviguer dans les menus affichés sur l'OLED pour :
    *   Consulter les tensions individuelles des cellules.
    *   Modifier les réglages à la volée (ex : forcer un mode "Stockage" à 50% de charge).
    *   Réinitialiser les erreurs éventuelles.

### **7.3. Supervision & Pilotage des Rails de Sortie**
Le BMS ne se contente pas de fournir de la puissance, il vérifie la qualité de ce qu'il délivre et contrôle la distribution :
*   **ADC de Monitoring (Feedback) :** Le RP2350 mesure en continu via ses ADCs les tensions réelles présentes sur les sorties de puissance. Cela permet de détecter une sous-tension (brownout) ou une défaillance d'un régulateur en aval.
*   **GPIOs "Enable" :** Chaque rail de puissance majeur (notamment les 4 sorties principales) est piloté par un commutateur de charge (*Load Switch*) activable individuellement par logiciel.
    *   *Scénario :* Le BMS peut choisir de couper l'alimentation des moteurs tout en gardant l'unité de calcul (BeagleBone) allumée en cas de batterie faible critique.

### **7.4. Gestion Thermique Active & Sécurité Étendue**
Compte tenu des puissances en jeu (jusqu'à 100W en crête), la gestion thermique est renforcée :
*   **NTC Additionnelles :** Des connecteurs pour sondes de température externes permettent de surveiller des points chauds spécifiques (ex: transistors de puissance, connecteurs forts courants).
*   **Pilotage Ventilateur (PWM) :** Une sortie PWM dédiée permet de piloter un micro-ventilateur. Le RP2350 asservit la vitesse du ventilateur à la température mesurée par les NTCs, assurant un refroidissement actif de l'étage de puissance lors des charges rapides ou des fortes sollicitations moteurs.

> **Synthèse I/O :** Cette panoplie d'interfaces transforme le BMS en un véritable **superviseur d'énergie**, offrant une observabilité totale et une capacité d'action autonome pour protéger le robot.

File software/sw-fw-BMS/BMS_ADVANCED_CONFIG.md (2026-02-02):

Voici le contenu complet et fusionné pour le fichier `BMS_ADVANCED_CONFIG.md`. J'ai intégré le script Python dans une nouvelle section **"Outils d'Automatisation"** à la fin du document.

***

# ⚙️ BMS Advanced Configuration & Data Flash

Ce document détaille les registres avancés du **BQ40Z50**. Contrairement aux mesures temps-réel, ces paramètres sont stockés dans la **Data Flash** du composant. Ils définissent le comportement physique et les sécurités du BMS.

> [!WARNING]
> **Attention :** Modifier ces valeurs modifie le comportement de sécurité de la batterie.
> 1. Le dispositif doit être en mode **UNSEALED** (déverrouillé) pour accepter l'écriture.
> 2. Une mauvaise configuration peut empêcher l'ouverture des MOSFETs ou endommager les cellules.

---

## 🔐 1. Structure de la Mémoire (Data Flash)

Pour configurer le BMS, on n'utilise pas les commandes I2C simples, mais on écrit dans des "Classes" et "Sous-classes".
* **Protocole :** SMBus Block Write
* **Adresse I2C :** `0x0B` (Smart Battery)

### 🔋 Configuration du Pack (Design)

Ces registres définissent l'architecture physique de votre batterie (4S3P dans notre cas).

| Classe | Sous-classe | Offset | Nom | Description | Valeur Type (4S) |
| :--- | :--- | :--- | :--- | :--- | :--- |
| **Settings** | Configuration | 0 | **DA Configuration** | Définit le nombre de cellules (Bitmask). | `0x00` (voir détail bas de page) |
| **Gas Gauging** | Design | 0 | **Design Capacity** | Capacité théorique du pack (mAh). | `10500` (3 x 3500mAh) |
| **Gas Gauging** | Design | 2 | **Design Energy** | Énergie théorique (cWh). | `1512` (151.2 Wh) |

### 🛡️ Sécurités & Protections (Safety)

Ces seuils déclenchent l'ouverture d'urgence des MOSFETs (Protection Matérielle).

| Protection | Registre (Class/Sub) | Nom | Seuil (Threshold) | Délai | Description |
| :--- | :--- | :--- | :--- | :--- | :--- |
| **CUV** | Protections / Voltage | **CUV Threshold** | 2800 mV | 2 s | **Cell Under Voltage**. Arrêt décharge si une cellule < 2.8V. |
| **COV** | Protections / Voltage | **COV Threshold** | 4250 mV | 2 s | **Cell Over Voltage**. Arrêt charge si une cellule > 4.25V. |
| **OCC** | Protections / Current | **OCC Threshold** | 6000 mA | 2 s | **Over Current Charge**. Courant charge max. |
| **OCD1** | Protections / Current | **OCD1 Threshold** | 20000 mA | 2 s | **Over Current Discharge**. Courant décharge max (Tier 1). |
| **OTC** | Protections / Temp | **OTC Threshold** | 55°C | 2 s | **Over Temp Charge**. Trop chaud pour charger. |

---

## 💡 2. Configuration des Périphériques (LEDs & GPIO)

Le BQ40Z50 peut piloter une jauge à LED (jusqu'à 5 segments) directement si le PCB est câblé pour.

**Location :** `Settings` -> `Configuration` -> `LED Configuration`

| Paramètre | Bit / Valeur | Fonction |
| :--- | :--- | :--- |
| **LED_ON** | Bit 0 | Si `1`, active la gestion des LEDs lors de l'appui bouton. |
| **LED_BLINK** | Bit 2 | Si `1`, les LEDs clignotent pendant la charge. |
| **CHG_IND** | Bit 3 | Indication visuelle de charge. |
| **LED Check** | N/A | La jauge s'active si le courant > seuil défini (Threshold). |

---

## 🛠️ 3. Commandes "Manufacturer Access" (MAC)

Ce sont des commandes exécutables envoyées au registre `0x44` (Little Endian) pour forcer des actions immédiates sans programmer la flash.

| Commande MAC (`0x44`) | Nom | Action / Effet |
| :--- | :--- | :--- |
| **`0x0001`** | **Device Type** | Renvoie le modèle (ex: `0x4500` pour BQ40Z50). |
| **`0x0021`** | **Gauging** | Active/Désactive l'algo d'apprentissage (Impedance Track). |
| **`0x0022`** | **FET Control** | **Force manuelle** des MOSFETs (Debug uniquement). |
| **`0x0041`** | **Device Reset** | Redémarre le processeur du BMS (Soft Reset). |
| **`0x0010`** | **Shutdown** | Met le BMS en veille profonde (Consommation ~0µA). Réveil via tension chargeur. |
| **`0x0030`** | **Seal Device** | Verrouille le BMS (Lecture seule) pour la production. |

---

## 📝 Note Technique : Configuration Cellules (DA Config)

Le registre **DA Configuration** est le plus critique. Il indique au BMS combien de cellules sont en série.
Pour un système 4S (BeagleBone Project) :

*   **Registre :** `Settings.Configuration.DA Configuration`
*   **Adresse Flash :** 0x45CC (dépend version firmware)
*   **Format :**
    *   **CC0 (Bit 0)** : Cell Count 0
    *   **CC1 (Bit 1)** : Cell Count 1

| Cellules | CC1 | CC0 | Hex Value (approx) |
| :--- | :---: | :---: | :--- |
| **3 Cells** | 1 | 0 | `0x02` |
| **4 Cells** | 1 | 1 | `0x03` |

> **Note :** Si ce registre est mal configuré, le BMS mesurera une tension totale erronée et se mettra en sécurité immédiate.

---

## 🐍 4. Outil d'Automatisation (Script Python)

Ce script MicroPython pour le RP2350 permet de modifier la Data Flash (ex: changer la capacité design).

**Fonctionnement :**
1. **Unseal :** Envoie les clés de sécurité (`0x0414`, `0x3672`) pour déverrouiller l'écriture.
2. **Write Flash :** Écrit un bloc de données avec calcul du Checksum obligatoire.
3. **Reset :** Redémarre le BMS pour appliquer la nouvelle config.

```python
from machine import I2C, Pin
import time
import struct

# --- CONFIGURATION I2C (RP2350) ---
SDA_PIN = 8
SCL_PIN = 9
I2C_FREQ = 400000
BMS_ADDR = 0x0B

# --- EXEMPLE: ADRESSES DATA FLASH (BQ40Z50) ---
# SubClass 48 (Gas Gauging) / Offset 0 = Design Capacity
DF_CLASS_GAS_GAUGING = 48 
DF_OFFSET_DESIGN_CAP = 0 

# Commandes SMBus Flash Access
CMD_MAC      = 0x00
CMD_DF_CLASS = 0x3E
CMD_DF_BLOCK = 0x3F
CMD_DF_DATA  = 0x40
CMD_DF_CSUM  = 0x60

i2c = I2C(0, scl=Pin(SCL_PIN), sda=Pin(SDA_PIN), freq=I2C_FREQ)

def bms_write_word_mac(command):
    """Ecrit une commande MAC en Little Endian"""
    payload = struct.pack('<H', command)
    i2c.writeto_mem(BMS_ADDR, CMD_MAC, payload)
    time.sleep(0.05)

def unseal_bms():
    """Déverrouille le BMS (Default Keys: 0x0414, 0x3672)"""
    print("🔓 UNSEAL BMS...")
    bms_write_word_mac(0x0414) # Key 1
    bms_write_word_mac(0x3672) # Key 2
    print("   -> Clés envoyées.")

def write_data_flash(class_id, offset, data_bytes):
    """Ecrit dans la Data Flash avec calcul de Checksum"""
    print(f"📝 Ecriture Flash | Class: {class_id}, Offset: {offset}")
    try:
        # 1. Setup Class & Block
        i2c.writeto_mem(BMS_ADDR, CMD_DF_CLASS, bytes([class_id]))
        i2c.writeto_mem(BMS_ADDR, CMD_DF_BLOCK, bytes([offset // 32]))
        
        # 2. Lire le bloc existant (32 bytes) pour ne pas corrompre le reste
        current_block = list(i2c.readfrom_mem(BMS_ADDR, CMD_DF_DATA, 32))
        
        # 3. Modifier les octets cibles
        local_idx = offset % 32
        for i, b in enumerate(data_bytes):
            if local_idx + i < 32:
                current_block[local_idx + i] = b
        
        # 4. Ecriture du nouveau bloc
        new_block_bytes = bytes(current_block)
        i2c.writeto_mem(BMS_ADDR, CMD_DF_DATA, new_block_bytes)
        
        # 5. Calcul et Envoi du Checksum (Spécifique TI)
        # Checksum = (255 - (Sum of (Class + Block + Data) % 256))
        total_sum = sum(new_block_bytes) + class_id + (offset // 32)
        checksum = (255 - (total_sum & 0xFF)) & 0xFF
        
        i2c.writeto_mem(BMS_ADDR, CMD_DF_CSUM, bytes([checksum]))
        print(f"   -> Succès ! Checksum: {hex(checksum)}")
        
    except Exception as e:
        print(f"❌ Erreur Flash : {e}")

def reset_bms():
    """Soft Reset du BMS pour recharger la Flash"""
    print("🔄 Reset BMS...")
    bms_write_word_mac(0x0041)

# --- MAIN SEQUENCE ---
if __name__ == "__main__":
    unseal_bms()
    time.sleep(1)
    
    # Exemple: Set Capacity = 10500 mAh (0x2904)
    # write_data_flash(DF_CLASS_GAS_GAUGING, DF_OFFSET_DESIGN_CAP, [0x04, 0x29])
    
    # reset_bms()
```

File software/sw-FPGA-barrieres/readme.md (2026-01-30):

# 🚧 Contrôleur de Barrière FPGA (SoC RISC-V)






## 📖 Description

Ce module contient le logiciel embarqué tournant sur le processeur softcore (VexRiscv) implémenté dans le FPGA. Il fait le lien entre le monde IoT (commandes MQTT via Ethernet) et le hardware (Drivers moteurs physiques).

Le programme interagit avec les registres matériels des contrôleurs de moteurs pas-à-pas via **Memory Mapped I/O (MMIO)** et s'abonne au broker MQTT pour recevoir les ordres d'ouverture/fermeture.

---

## ⚡ Démarrage Automatique (Autorun)

Le système est conçu pour être autonome. Une fois le bitstream (Gateware) chargé sur la FPGA, le SoC démarre et cherche un système de fichiers sur la carte SD.

**Dossier :** `gateware/fpga/sd-image/`

### Préparation de la Carte SD
1. **Compilation (si modification du code C) :**
   Assurez-vous que le binaire `v4` à jour est présent dans le dossier image.
   ```bash
   # Exemple de copie après compilation
   cp software/sw-FPGA-barrieres/v4 gateware/fpga/sd-image/
   ```

2. **Copie sur SD :**
   * Formater la carte SD en **FAT32**.
   * Copier l'intégralité du contenu du dossier `gateware/fpga/sd-image/` à la racine de la carte.

3. **Lancement :**
   * Insérer la carte dans le slot de la Nexys A7.
   * Charger le bitstream via Vivado.
   * Le système démarre automatiquement.

> **Mécanisme :** Le fichier `startup.sh` présent à la racine est exécuté automatiquement au boot de Linux. Il configure le réseau et lance le binaire `v4` avec la configuration par défaut.
---
## 🛠 Compilation (Cross-Compile)

Le code C ne peut pas être compilé avec le `gcc` de votre PC (x86), il doit être compilé pour l'architecture RISC-V cible.

**Pré-requis :** Toolchain Buildroot générée.

```bash
# Exemple de commande de compilation pour la version finale (v4)
~/parking_fpga/buildroot/output/host/bin/riscv32-buildroot-linux-gnu-gcc \
    src/v4-run-multiple.c \
    -o bin/v4 \
    -march=rv32ima \
    -mabi=ilp32 \
    -lmosquitto
```

* `-lmosquitto` : Link avec la librairie client MQTT.
* `-march=rv32ima` : Architecture RISC-V 32-bits (Integer, Multiply, Atomic).

---

## 📜 Historique des Versions

Le développement du driver a suivi une approche itérative, passant d'un test simple à un gestionnaire multi-barrières robuste.

### v0 : Version Initiale (Preuve de Concept)
* **Fichier :** `v0-test-concept.c`
* **Fonctionnalité :** Contrôle une seule barrière à l'adresse hardcodée `0xF0000000`.
* **Logique :** Séquence de rotation fixe (tableaux statiques). Bloque l'exécution pendant le mouvement.
* **MQTT :** Topic global simple `parking/barrier`.

### v1 : Gestion des IDs et du Sens (Soft)
* **Fichier :** `v1-ids-sens.c`
* **Nouveauté :** Introduction des arguments CLI (`./v1 [ID]`).
* **Topics Dynamiques :** `parking/barrier_{ID}/state`.
* **Inversion Logique :** Ajout du paramètre "Sens" pour compenser le montage physique (Moteur à gauche ou à droite) sans recâblage.
* *Limite :* Pilote toujours la même adresse physique, quel que soit l'ID.

### v2 : Mode Calibration & Test
* **Fichier :** `v2-configuration.c`
* **Objectif :** Outil de diagnostic pour déterminer le nombre de pas exact pour 90°.
* **Mode RAW :** Pas d'état "Ouvert/Fermé", mais des commandes directes de pas via MQTT (`parking/test`).
    * `p64` : 64 pas sens Positif.
    * `m128` : 128 pas sens Minus.
* **Résultat :** A permis de fixer la constante `CYCLES_REQUIRED = 128`.

### v3 : Support Multi-Adresses (Hardware)
* **Fichier :** `v3-multiple-adress.c`
* **Nouveauté :** Mapping réel des adresses physiques.
* **Table de Mapping :** Associe un ID logiciel (0, 1...) à une adresse AXI physique (`0xF0000000`, `0xF0000800`...).
* **Usage :** Nécessite de lancer une instance du programme par barrière physique.

### 🌟 v4 : Architecture Unifiée (Finale)
* **Fichier :** `v4-run-multiple.c`
* **Architecture :** Gestionnaire unique (Single Process) pour tout le parking.
* **Optimisation :** Une seule connexion MQTT partagée. Structure C objet (`struct Barrier`) pour isoler les états.
* **CLI Avancée :** Configuration au lancement sous la forme `ID:SENS`.
    * Exemple : `./v4 0:1 2:0` (Lance Barrière 0 en sens inversé et Barrière 2 en sens normal).
* **Déploiement :** C'est cette version qui est lancée par le `startup.sh`.

---

## 📡 Utilisation MQTT

Pour piloter une barrière depuis le réseau (ou la BeagleBone) :

```bash
# Ouvrir la barrière 0
mosquitto_pub -h 192.168.78.2 -t "parking/barrier_0/state" -m "OPEN"

# Fermer la barrière 0
mosquitto_pub -h 192.168.78.2 -t "parking/barrier_0/state" -m "CLOSE"

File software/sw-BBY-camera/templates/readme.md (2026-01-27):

# Interface Web (Templates)





## 📖 Vue d'ensemble

Ce dossier contient les fichiers HTML utilisés par le serveur Flask pour générer l'interface utilisateur.
L'interface est conçue en **Dark Mode** natif pour limiter la fatigue visuelle et utilise du **JavaScript pur (Vanilla JS)** pour les mises à jour dynamiques (AJAX) sans rechargement de page.

---

## 📂 Détail des Vues

### 1. Portail de Connexion (`login.html`)
Point d'entrée sécurisé de l'application.

* **Fonctionnalités :**
    * Formulaire d'authentification (Utilisateur / Admin).
    * Bouton "Afficher/Masquer" le mot de passe.
    * Modale "Mot de passe oublié" (Simulation frontend).
* **Design :** Carte centrée avec ombres portées et design épuré `Segoe UI`.

### 2. Console Administrateur (`index.html`)
Le centre de contrôle pour l'équipe IT (`role: IT`).

* **Supervision Temps Réel :**
    * **Vidéosurveillance :** Affiche les flux des caméras Entrée/Sortie (simulés ou réels).
    * **Logs MQTT :** Console défilante affichant les événements système (Passage de badge, Ouverture barrière).
* **Historique Global :** Tableau complet des mouvements avec une barre de défilement verticale pour naviguer dans les archives.
* **Technique :** Utilise `setInterval` et `fetch` pour rafraîchir les données toutes les secondes.

### 3. Espace Conducteur (`dashboard.html`)
L'interface personnelle pour les utilisateurs finaux (`role: USER`).

* **Gestion Flotte :** Affiche les véhicules de l'utilisateur sous forme de cartes.
    * Indique l'état actuel : **GARÉ** (Vert) ou **SORTI** (Orange).
    * Calcule la durée de stationnement en temps réel.
* **Calendrier Visuel :** Historique personnel affiché sous forme de calendrier interactif (les jours d'activité sont cliquables).
* **Profil :** Modale permettant de mettre à jour son email et son numéro de téléphone via une API REST.

---

## ⚙️ Comment tester ces interfaces ?

Ces fichiers ne peuvent pas être ouverts directement dans un navigateur (le code `{{ variable }}` ne fonctionnerait pas).

Pour les visualiser, lancez le serveur de rendu dans le dossier `test/` :

```bash
cd ../test
python3 test_server_render.py

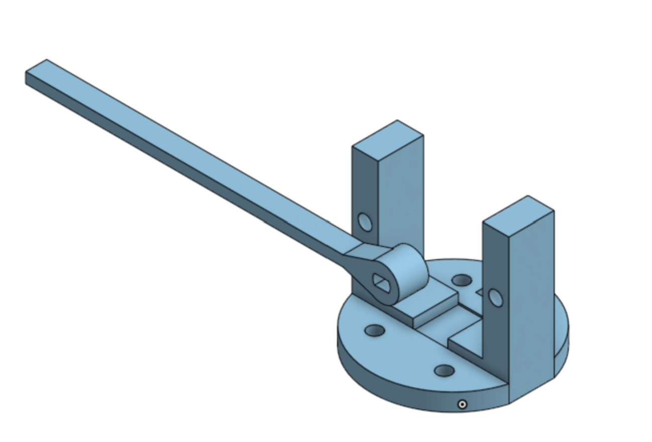
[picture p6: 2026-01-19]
hardware/model3D/barrière/rendu3D.png

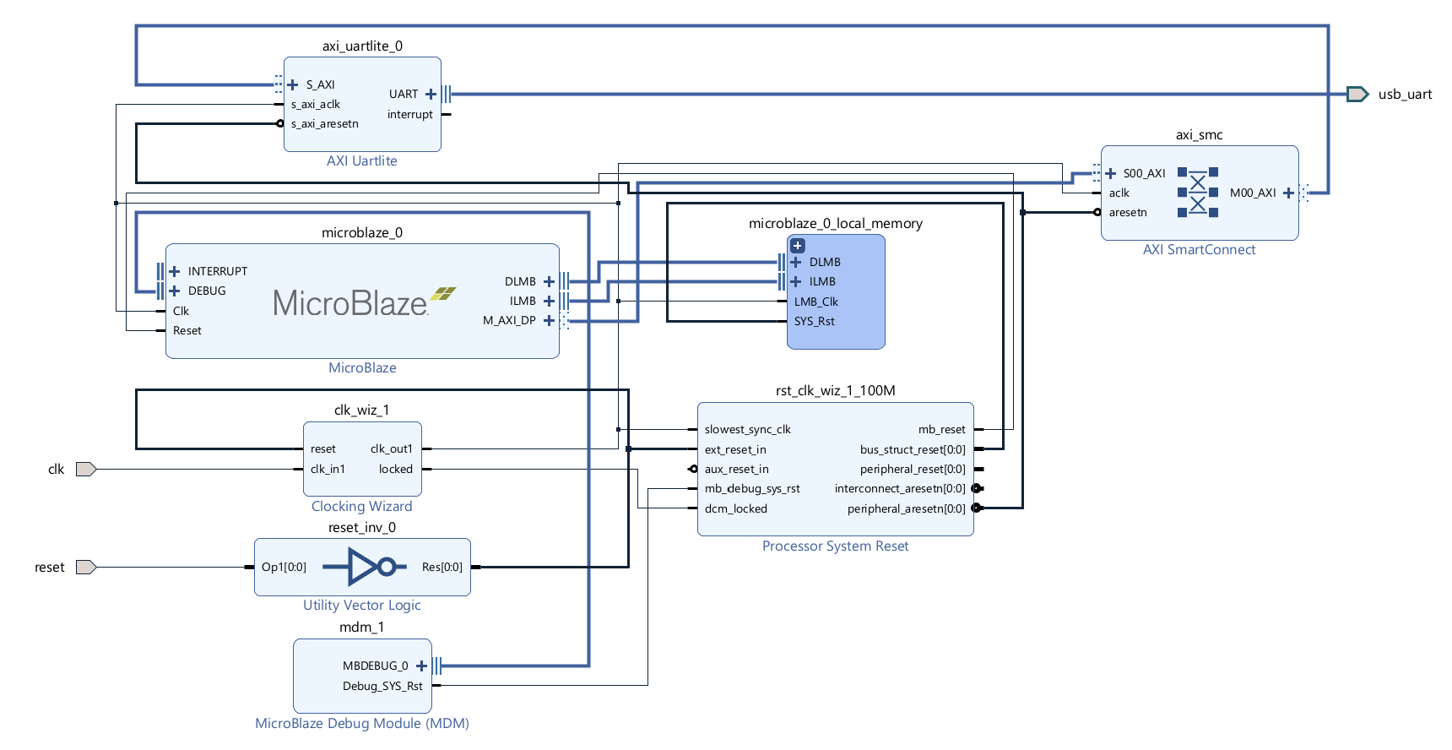
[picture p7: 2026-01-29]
gateware/fpga/v0-test-minimal-soc/block-design-microblaze.png

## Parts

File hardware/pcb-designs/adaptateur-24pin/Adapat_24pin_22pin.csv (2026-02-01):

Reference | Qty | Value | DNP | Exclude from BOM | Exclude from Board | Footprint | Datasheet | JLCPCB
C1 | 1 | 100n |  |  |  | Capacitor_SMD:C_0603_1608Metric_Pad1.08x0.95mm_HandSolder | ~ | C77050
H1,H2,H3,H4 | 4 | MountingHole |  | Exclure de la Liste du Matériel |  | MountingHole:MountingHole_2.2mm_M2 | ~
J1 | 1 | Conn_01x24_Pin |  |  |  | Connector_FFC-FPC:Hirose_FH12-24S-0.5SH_1x24-1MP_P0.50mm_Horizontal | ~ | C202112
J2 | 1 | Conn_01x22_Pin |  |  |  | Connector_FFC-FPC:Hirose_FH12-22S-0.5SH_1x22-1MP_P0.50mm_Horizontal | ~ | C597981
J3 | 1 | Conn_01x04_Pin |  |  |  | Connector_PinSocket_2.54mm:PinSocket_1x04_P2.54mm_Horizontal | ~ | C5252508
R1 | 1 | 33 |  |  |  | Resistor_SMD:R_0603_1608Metric_Pad0.98x0.95mm_HandSolder | ~ | C209118
SW1 | 1 | SW_SPDT |  |  |  | Custom-Vincent:C223846 | ~ | C223846
Y1 | 1 | XO32 |  |  |  | Oscillator:Oscillator_SMD_EuroQuartz_XO32-4Pin_3.2x2.5mm | http://cdn-reichelt.de/documents/datenblatt/B400/XO32.pdf | C160455

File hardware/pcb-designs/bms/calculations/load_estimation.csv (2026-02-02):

PARAMETRES GLOBAUX | VALEUR | UNITE | COMMENTAIRE
ENERGIE BATTERIE (Wh) | 151,2 | Wh | Pack 4S3P (14,4V * 10,5Ah)
APPORT SOLAIRE (W) | 50 | W | Panneau via USB-PD
COMPOSANT | TENSION (V) | COURANT MAX (A) | PUISSANCE MAX (W) | PUISSANCE MOY (W) | COMMENTAIRE
BeagleBone AI-64 | 5 | 3 | 15 | 10 | CPU/GPU charge lourde
FPGA Nexys A7 | 5 | 1 | 5 | 2,5 | Logique programmee
STM32 & Capteurs | 3,3 | 0,5 | 1,65 | 0,5 | MCU Control loop
Moteurs (Driver) | 16,8 | 2,5 | 42 | 25 | Pics d'acceleration vs croisiere
BMS (Logique + Pertes) | 3,3 | 0,3 | 0,99 | 0,5 | Conso propre + rendement conv.
Ventilateur & OLED | 5 | 0,4 | 2 | 1,5 | Refroidissement actif si > 40C
TOTAL THEORIQUE |  |  | 66,64 | 40 | Somme des consos
Marge de sécurité 20% |  | "+20%" | 79,97 | 48
SCENARIOS D'USAGE | PUISSANCE (W) | AUTONOMIE BATTERIE (H) | AUTONOMIE AVEC SOLAIRE (H) | NOTES
Mode Repos (Idle) mesuré | 18 | 8,4 | INFINI | Charge batterie (<Excedent solaire)
Mode Mixte (Standard) | 48 | 3,15 | INFINI | Charge batterie (Excedentfaible)
Mode Intensif (Full Load) | 66,64 | 2,27 | 9,09 | Decharge lente (Pointe de consommation)
Mode Intensif + 20% | 79,97 | 1,89 | 5,05 | Decharge moyenne mais suffisante
BILAN SMART GRID (SOLAIRE) | VALEUR | UNITE | FORMULE / COMMENTAIRE
Apport Solaire | 50 | W | Reference cellule B3
Charge Robot (Intensif) | 79,968 | W | Reference Mode Intensif
Soulagement Batterie | 0 | % | Apport/Charge
Gain Autonomie | 2,668446343 | x | Autonomie Solaire / Autonomie Sans

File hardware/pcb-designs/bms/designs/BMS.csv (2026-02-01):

Reference | Qty | Value | DNP | Exclude from BOM | Exclude from Board | Footprint | Datasheet | Number-JLCPCB | Description
R5 | 1 | 33 |  |  |  | Resistor_SMD:R_0402_1005Metric | ~ | C25105 | Resistor
R17 | 1 | 20k |  |  |  | Resistor_SMD:R_0603_1608Metric_Pad0.98x0.95mm_HandSolder | ~ | C4184 | Resistor
R22 | 1 | 150k |  |  |  | Resistor_SMD:R_0603_1608Metric_Pad0.98x0.95mm_HandSolder | ~ | C22807 | Resistor
R23 | 1 | 40.2k |  |  |  | Resistor_SMD:R_0402_1005Metric_Pad0.72x0.64mm_HandSolder | ~ | C25893 | Resistor
R24 | 1 | 137k |  |  |  | Resistor_SMD:R_0603_1608Metric_Pad0.98x0.95mm_HandSolder | ~ | C22872 | Resistor
R25 | 1 | 30.1k |  |  |  | Resistor_SMD:R_0603_1608Metric_Pad0.98x0.95mm_HandSolder | ~ | C23000 | Resistor
R26 | 1 | 3.3k |  |  |  | Resistor_SMD:R_0603_1608Metric_Pad0.98x0.95mm_HandSolder | ~ | C22978 | Resistor
R31 | 1 | 2M |  |  |  | Resistor_SMD:R_0603_1608Metric_Pad0.98x0.95mm_HandSolder | ~ | C22976 | Resistor
R33 | 1 | 64.9k |  |  |  | Resistor_SMD:R_0603_1608Metric_Pad0.98x0.95mm_HandSolder | ~ | C137692 | Resistor
R35 | 1 | 120k |  |  |  | Resistor_SMD:R_0603_1608Metric_Pad0.98x0.95mm_HandSolder | ~ | C114607 | Resistor
R36 | 1 | 280k |  |  |  | Resistor_SMD:R_0603_1608Metric_Pad0.98x0.95mm_HandSolder | ~ | C22970 | Resistor
R40 | 1 | 200k |  |  |  | Resistor_SMD:R_0603_1608Metric_Pad0.98x0.95mm_HandSolder | ~ | C25811 | Resistor
R41 | 1 | 13k |  |  |  | Resistor_SMD:R_0603_1608Metric_Pad0.98x0.95mm_HandSolder | ~ | C22970 | Resistor
R42 | 1 | 4k7 |  |  |  | Resistor_SMD:R_0603_1608Metric_Pad0.98x0.95mm_HandSolder | ~ | C23162 | Resistor
R43 | 1 | 4k87 |  |  |  | Resistor_SMD:R_0603_1608Metric_Pad0.98x0.95mm_HandSolder | ~ | C23045 | Resistor
R44 | 1 | 8k66 |  |  |  | Resistor_SMD:R_0603_1608Metric_Pad0.98x0.95mm_HandSolder | ~ | C23114 | Resistor
R46 | 1 | 820 |  |  |  | Resistor_SMD:R_0603_1608Metric_Pad0.98x0.95mm_HandSolder | ~ | 0603 | Resistor
R50 | 1 | 2k |  |  |  | Resistor_SMD:R_0603_1608Metric_Pad0.98x0.95mm_HandSolder | ~ | C22975 | Resistor
R61 | 1 | 5.1 |  |  |  | Resistor_SMD:R_0402_1005Metric_Pad0.72x0.64mm_HandSolder | ~ | C482216 | Resistor
R65 | 1 | 300 |  |  |  | Resistor_SMD:R_2512_6332Metric_Pad1.40x3.35mm_HandSolder | ~ | C25482 | Resistor
R66 | 1 | 51k |  |  |  | Resistor_SMD:R_0603_1608Metric_Pad0.98x0.95mm_HandSolder | ~ | C18672 | Resistor
R84 | 1 | 22k |  |  |  | Resistor_SMD:R_0603_1608Metric_Pad0.98x0.95mm_HandSolder | ~ | C23344 | Resistor
R85 | 1 | 60 |  |  |  | Resistor_SMD:R_0603_1608Metric_Pad0.98x0.95mm_HandSolder | ~ | C76816 | Resistor
RS1 | 1 | 1 |  |  |  | Resistor_SMD:R_0805_2012Metric_Pad1.20x1.40mm_HandSolder | ~ | C3009412 | Resistor
R6,R7 | 2 | 1k |  |  |  | Resistor_SMD:R_0402_1005Metric | ~ | C2773862 | Resistor
R8,R9 | 2 | 27 |  |  |  | Resistor_SMD:R_0402_1005Metric | ~ | C25190 | Resistor
R10,R15 | 2 | 10 |  |  |  | Resistor_SMD:R_1206_3216Metric_Pad1.30x1.75mm_HandSolder | ~ | C17903 | Resistor
R18,R19 | 2 | 4.99 |  |  |  | Resistor_SMD:R_0603_1608Metric_Pad0.98x0.95mm_HandSolder | ~ | C23165 | Resistor
R30,R34 | 2 | 300k |  |  |  | Resistor_SMD:R_0603_1608Metric_Pad0.98x0.95mm_HandSolder | ~ | C844772 | Resistor
R90,R98 | 2 | 47k |  |  |  | Resistor_SMD:R_0603_1608Metric_Pad0.98x0.95mm_HandSolder | ~ | C844929 | Resistor
R93,R101 | 2 | 365 |  |  |  | Resistor_SMD:R_0805_2012Metric_Pad1.20x1.40mm_HandSolder | ~ | C63500 | Resistor
R106,R112 | 2 | 3296W-1-502LF |  |  |  | Custom-Vincent:3296W1503LF | https://componentsearchengine.com/Datasheets/2/3296W-1-502LF.pdf | C60620 | 3296W top adj cermet trimmer,5K 10mm Bourns 3296W Series 25-Turn Through Hole Cermet Trimmer Resistor with Pin Terminations, 5k +/-10% 1/2W +/-100ppm/C
R109,R115 | 2 | 180k |  |  |  | Resistor_SMD:R_0603_1608Metric_Pad0.98x0.95mm_HandSolder | ~ | C844744 | Resistor
R20,R38,R39 | 3 | 10 |  |  |  | Resistor_SMD:R_0603_1608Metric_Pad0.98x0.95mm_HandSolder | ~ | C313648 | Resistor
R60,R70,R74 | 3 | 10M |  |  |  | Resistor_SMD:R_0603_1608Metric_Pad0.98x0.95mm_HandSolder | ~ | C2090725 | Resistor
RS2,RS3,RS4 | 3 | 0.01 |  |  |  | Resistor_SMD:R_1206_3216Metric_Pad1.30x1.75mm_HandSolder | https://www.mouser.fr/ProductDetail/Vishay-Dale/WSLP1206R0100FEA?qs=eFWhpKjIuGi0NI6XY8kkuw%3D%3D | C844910 | Resistor
R75,R76,R78,R79 | 4 | 200 |  |  |  | Resistor_SMD:R_0603_1608Metric_Pad0.98x0.95mm_HandSolder | ~ | C8218 | Resistor
R91,R99,R110,R116 | 4 | 33k |  |  |  | Resistor_SMD:R_0603_1608Metric_Pad0.98x0.95mm_HandSolder | ~ | C4216 | Resistor
R92,R100,R107,R113 | 4 | 121 |  |  |  | Resistor_SMD:R_0805_2012Metric_Pad1.20x1.40mm_HandSolder | ~ | C317367 | Resistor
R63,R67,R68,R69,R72 | 5 | 5.1k |  |  |  | Resistor_SMD:R_0603_1608Metric_Pad0.98x0.95mm_HandSolder | ~ | C2774420 | Resistor
R11,R52,R53,R54,R55,R82,R88 | 7 | 1k |  |  |  | Resistor_SMD:R_0603_1608Metric_Pad0.98x0.95mm_HandSolder | ~ | C844748 | Resistor
R12,R13,R80,R95,R103,R108,R114 | 7 | 3.9 |  |  |  | Resistor_SMD:R_1206_3216Metric_Pad1.30x1.75mm_HandSolder | https://www.mouser.fr/ProductDetail/Vishay/CRCW12063R90JNEA?qs=RBLAFTxbykx6FwOAglFQuA%3D%3D | C74090 | Resistor
R3,R4,R51,R56,R57,R58,R59,R62,R64,R71,R81,R87 | 12 | 100 |  |  |  | Resistor_SMD:R_0603_1608Metric_Pad0.98x0.95mm_HandSolder | ~ | C4264306 | Resistor
R1,R2,R16,R21,R37,R45,R48,R83,R86,R89,R97,R105,R111 | 13 | 100k |  |  |  | Resistor_SMD:R_0603_1608Metric_Pad0.98x0.95mm_HandSolder | ~ | C14675 | Resistor
R14,R27,R28,R29,R32,R47,R49,R73,R77,R94,R96,R117,R118 | 13 | 10k |  |  |  | Resistor_SMD:R_0603_1608Metric_Pad0.98x0.95mm_HandSolder | ~ | C169103 | Resistor

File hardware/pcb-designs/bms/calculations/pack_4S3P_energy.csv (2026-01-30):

PARAMETRE | VALEUR | UNITE | COMMENTAIRE
CELLULE INDIVIDUELLE (Samsung INR18650-35E)
Tension Nominale | 3.6 | V | Tension moyenne
Tension Max (Charge) | 4.2 | V | Pleine charge
Tension Min (Cut-off) | 2.65 | V | Décharge profonde (datasheet)
Capacité Typique | 3500 | mAh | Donnée constructeur
Capacité Retenue (Design) | 3400 | mAh | Marge de sécurité (conservative)
Courant Max Décharge | 8 | A | Continu
CONFIGURATION DU PACK (4S3P)
Nombre de cellules série (S) | 4 |  | Augmente la tension
Nombre de cellules parallèle (P) | 3 |  | Augmente la capacité/courant
Total Cellules | 12 | pcs
CARACTERISTIQUES DU PACK
Tension Nominale Pack | 14.4 | V | 3.6V * 4
Tension Max Pack | 16.8 | V | 4.2V * 4 (Tension CV)
Tension Min Pack (Safe) | 12.0 | V | 3.0V * 4 (Seuil BMS soft)
Capacité Totale | 10.2 | Ah | 3.4Ah * 3
Energie Totale | 146.9 | Wh | Nominale (14.4V * 10.2Ah)
Energie Max Théorique | 151.0 | Wh | Basé sur 14.8V moy
Courant Max Continu | 24 | A | 8A * 3
Puissance Max Continue | 345.6 | W | 14.4V * 24A

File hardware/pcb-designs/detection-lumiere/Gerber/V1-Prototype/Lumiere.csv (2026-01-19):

'Reference' | 'Qty' | 'Value' | 'DNP' | 'Exclude from BOM' | 'Exclude from Board' | 'Footprint' | 'Datasheet' | 'Number-JLCPCB'
'H1,H2,H5,H6' | '4' | 'MountingHole' | '' | 'Exclure de la Liste du Matériel' | '' | 'MountingHole:MountingHole_2.7mm_M2.5' | '~' | ''
'TP1,TP2,TP11' | '3' | 'TestPoint' | '' | 'Exclure de la Liste du Matériel' | '' | 'TestPoint:TestPoint_THTPad_2.0x2.0mm_Drill1.0mm' | '~' | ''
'RVAR1' | '1' | '3296W-1-502LF' | '' | '' | '' | 'Custom-Vincent:3296W1503LF' | 'https://componentsearchengine.com/Datasheets/2/3296W-1-502LF.pdf' | 'C60620'
'C4' | '1' | '100n' | '' | '' | '' | 'Capacitor_SMD:C_0603_1608Metric_Pad1.08x0.95mm_HandSolder' | '~' | 'C77050'
'U2' | '1' | 'LM311' | '' | '' | '' | 'Package_DIP:DIP-8_W7.62mm' | 'https://www.st.com/resource/en/datasheet/lm311.pdf' | 'C434572'
'J4' | '1' | 'Conn_01x01_Pin' | '' | '' | '' | 'Connector_PinHeader_2.54mm:PinHeader_1x01_P2.54mm_Vertical' | '~' | 'C492400'
'R2' | '1' | '47k' | '' | '' | '' | 'Resistor_SMD:R_0805_2012Metric_Pad1.20x1.40mm_HandSolder' | '~' | 'C844929'
'R1' | '1' | 'R_Photo' | '' | '' | '' | 'Custom-Vincent:NSL19M51' | '~' | 'C17518372'
'J8' | '1' | 'Conn_01x02' | '' | '' | '' | 'JST_XH_B2B-XH-A_1x02_P2.50mm_Vertical' | '~' | 'C32713268'

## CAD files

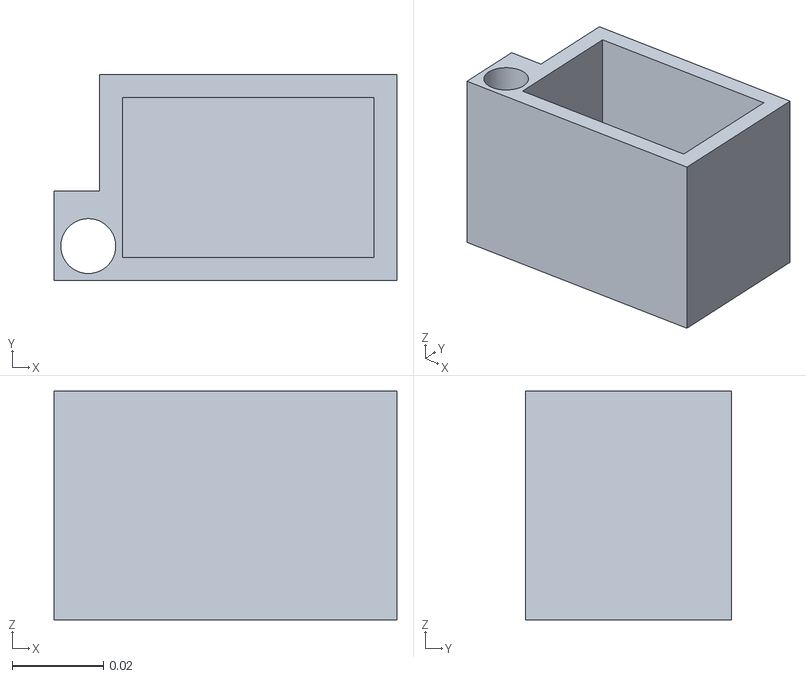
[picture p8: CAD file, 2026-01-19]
hardware/model3D/bloc-ascenseur/Support plateforme.stl
0.075 x 0.045 x 0.05

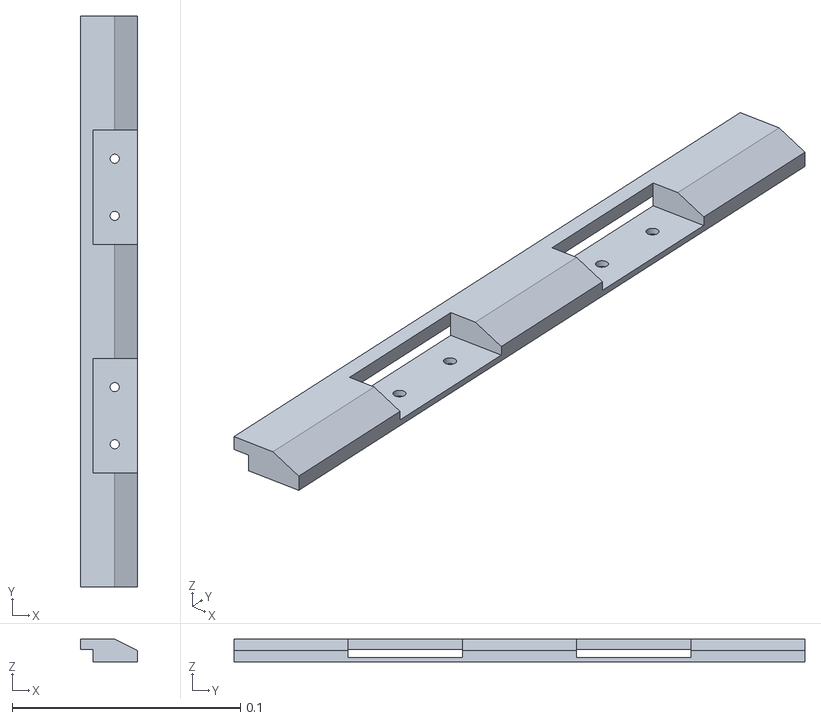
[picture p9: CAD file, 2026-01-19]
hardware/model3D/boitier-rfid/support-rail-rfid.stl
0.025 x 0.25 x 0.01

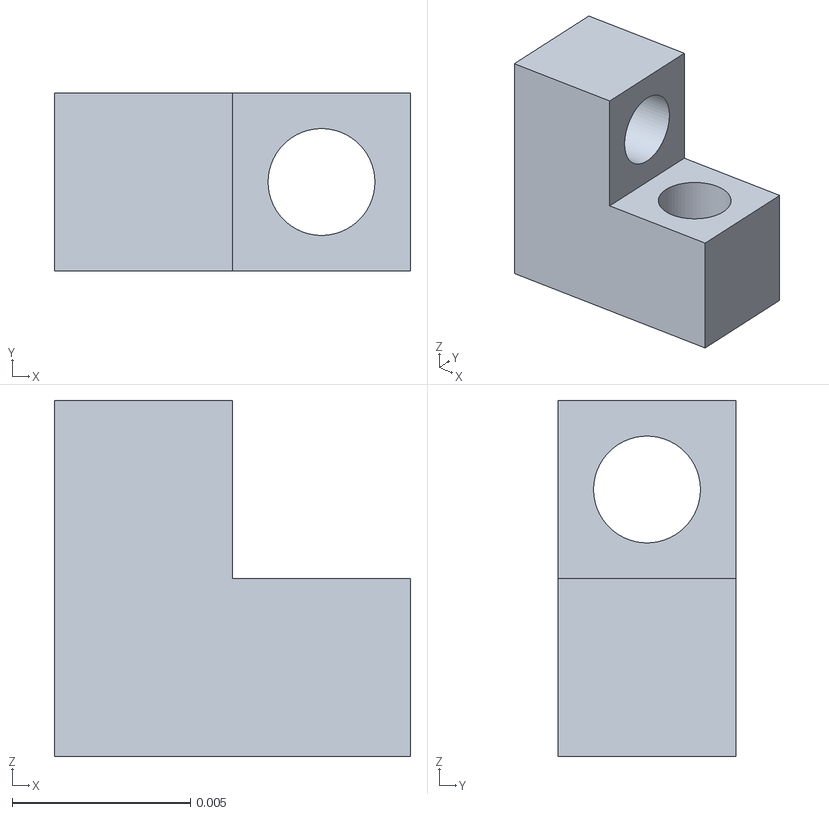
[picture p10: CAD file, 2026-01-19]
hardware/model3D/support-en-L.stl
0.01 x 0.005 x 0.01

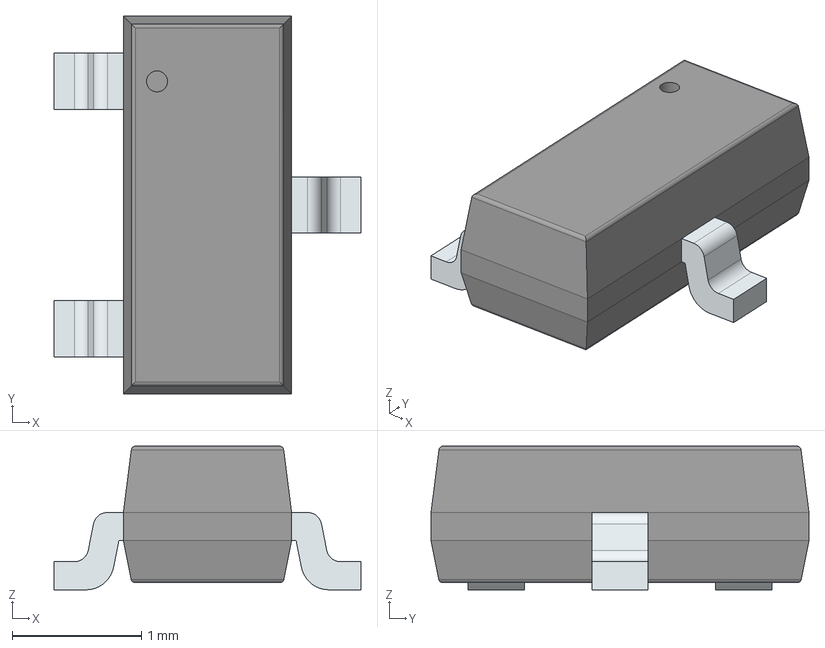
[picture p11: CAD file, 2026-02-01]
hardware/pcb-designs/common-libs/2N7002ET1G/3D/2N7002ET1G.stp
2.37 x 2.92 x 1.11 mm
PinsArrayL
FilletPinR

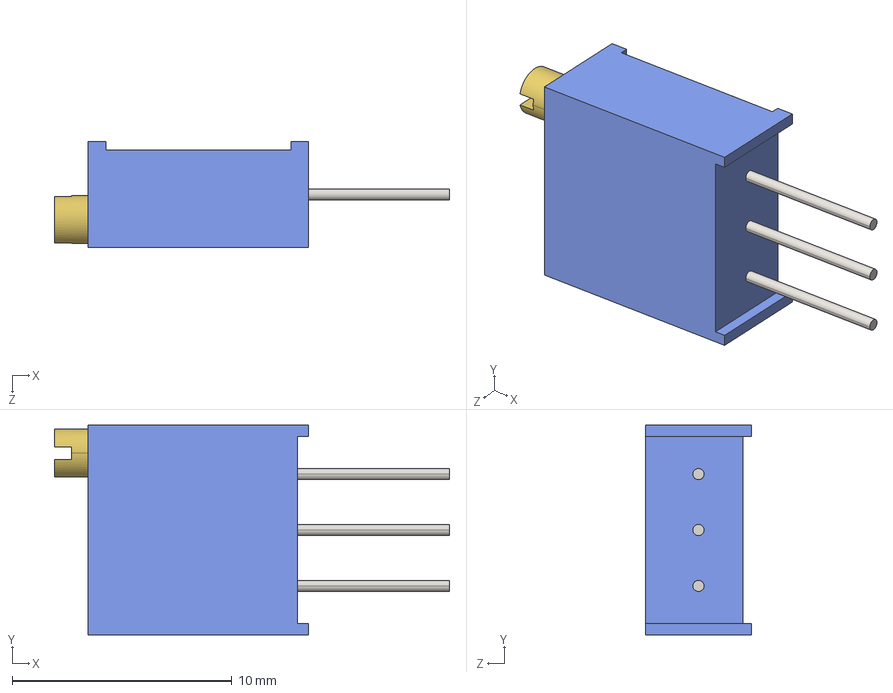
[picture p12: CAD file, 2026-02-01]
hardware/pcb-designs/common-libs/3296W-1-502LF/3D/3296W-1-502LF.stp
18.0 x 9.52 x 4.83 mm

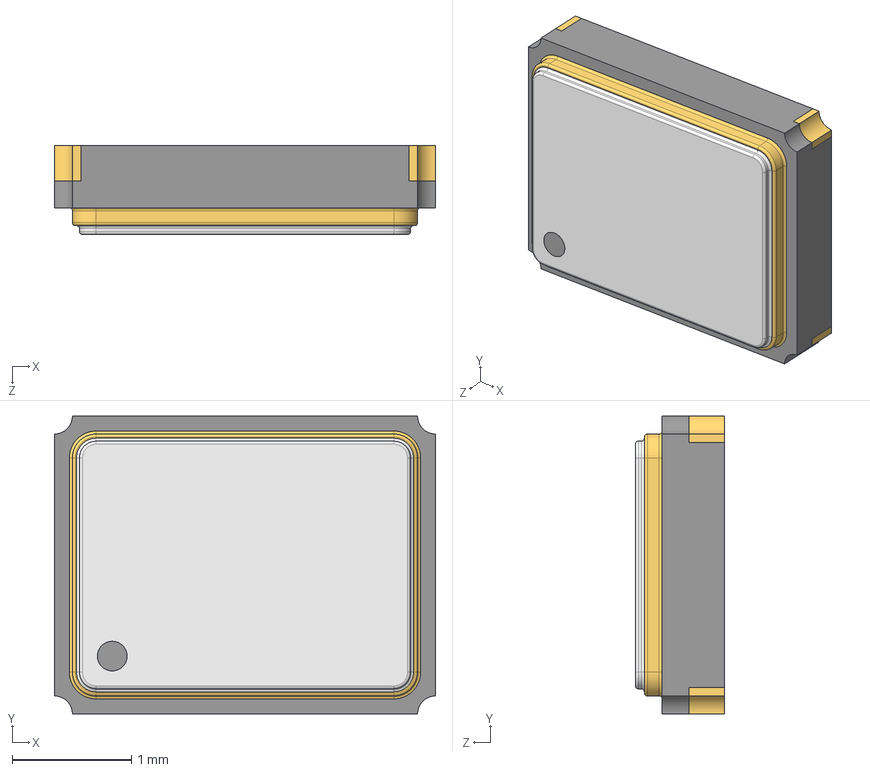
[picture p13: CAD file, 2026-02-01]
hardware/pcb-designs/common-libs/ABM8-272-T3/3D/ABM8-272-T3.stp
3.20 x 2.50 x 0.75 mm

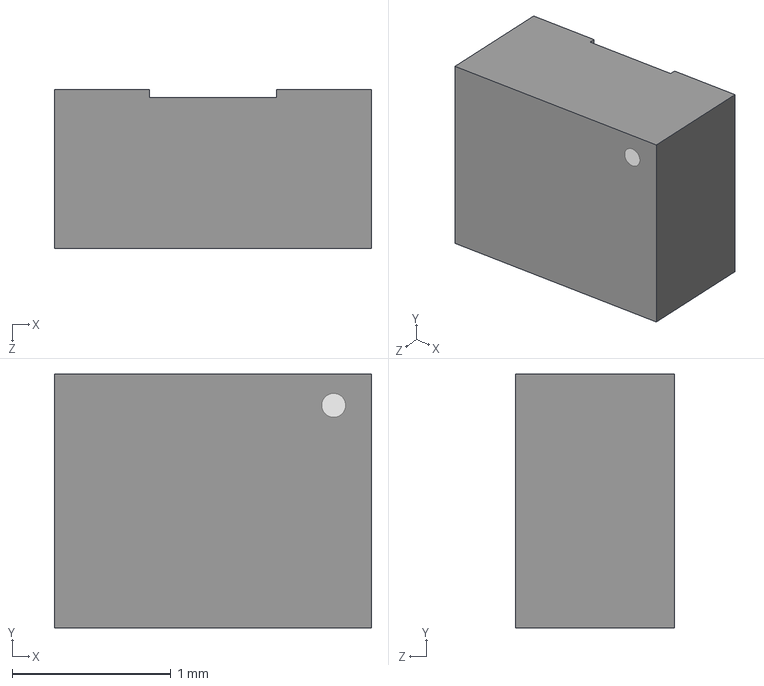
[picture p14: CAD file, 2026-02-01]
hardware/pcb-designs/common-libs/AOTA-B201610S3R3-101-T/3D/AOTA-B201610S3R3-101-T.stp
2.00 x 1.60 x 1.00 mm

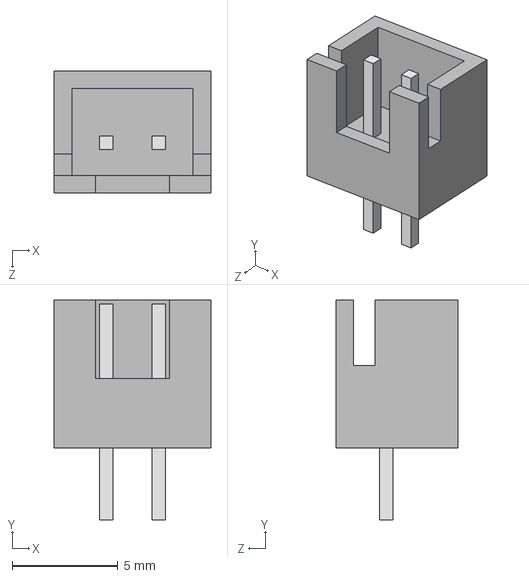
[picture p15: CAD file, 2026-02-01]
hardware/pcb-designs/common-libs/B2B-XH-A/3D/B2B-XH-A-GU.stp
7.40 x 10.4 x 5.75 mm

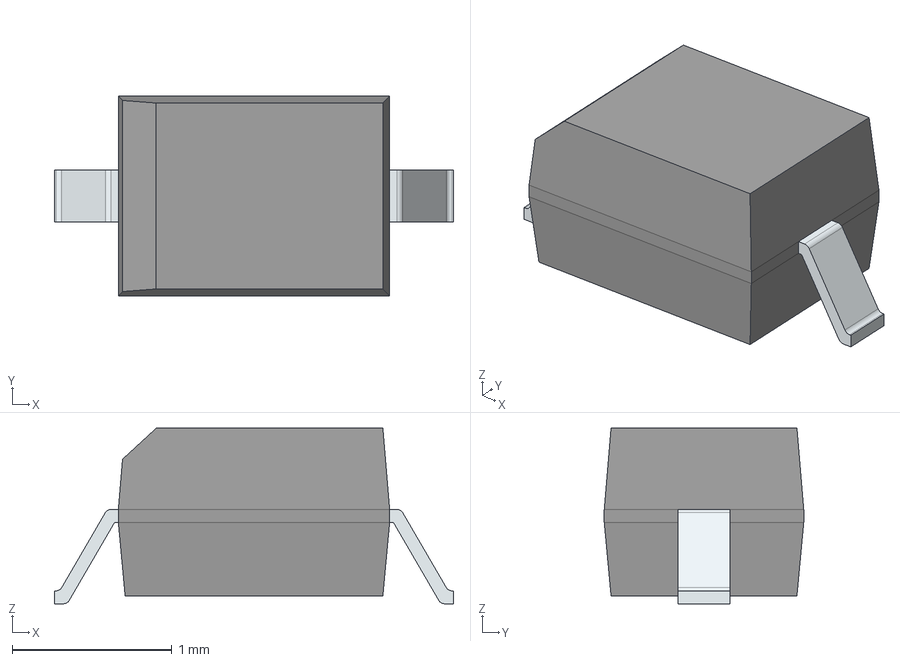
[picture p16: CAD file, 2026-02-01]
hardware/pcb-designs/common-libs/BAT54HT1G/3D/BAT54HT1G.stp
2.50 x 1.25 x 1.10 mm
FilletPinL
FilletPinR

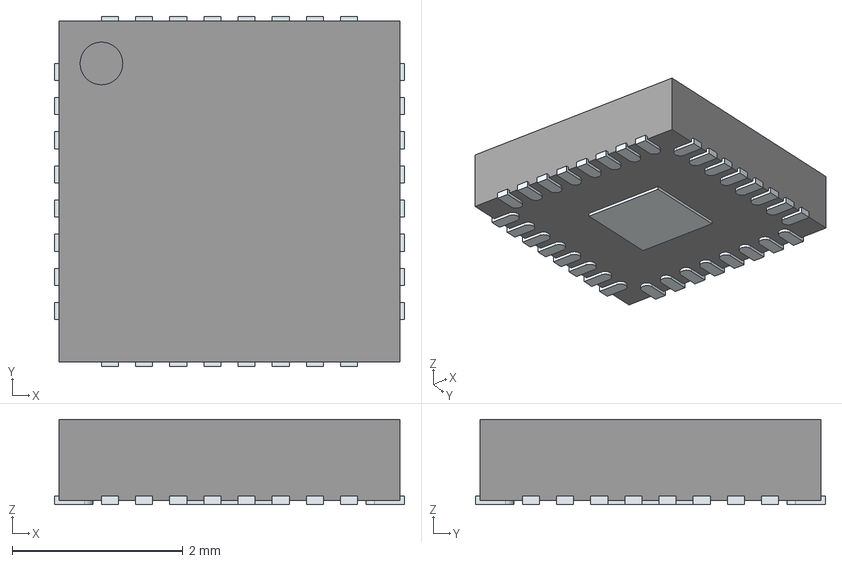
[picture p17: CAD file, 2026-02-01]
hardware/pcb-designs/common-libs/BQ40Z50RSMR-R2/3D/BQ40Z50RSMR-R2.stp
4.10 x 4.10 x 1.00 mm
ThermalPin
PinsArrayLR
PinsArrayTB

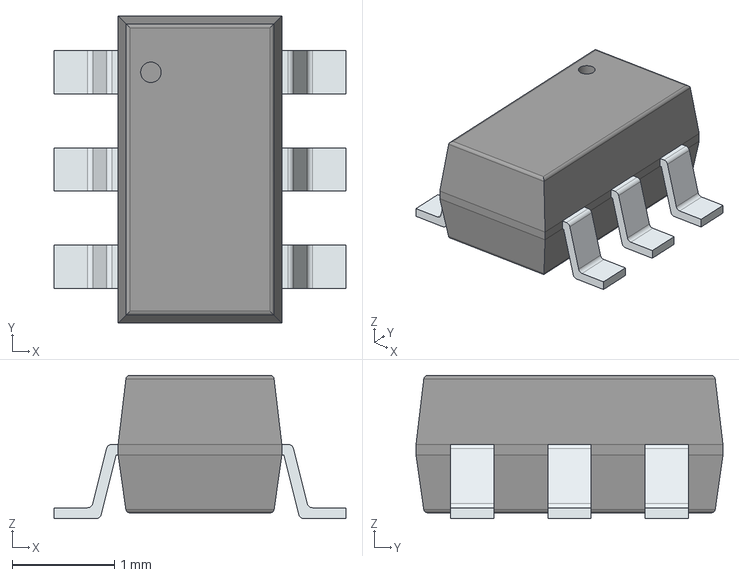
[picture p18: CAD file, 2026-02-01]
hardware/pcb-designs/common-libs/DCX124EK-7-F/3D/DCX124EK-7-F.stp
2.85 x 3.00 x 1.40 mm
PinsArrayLR

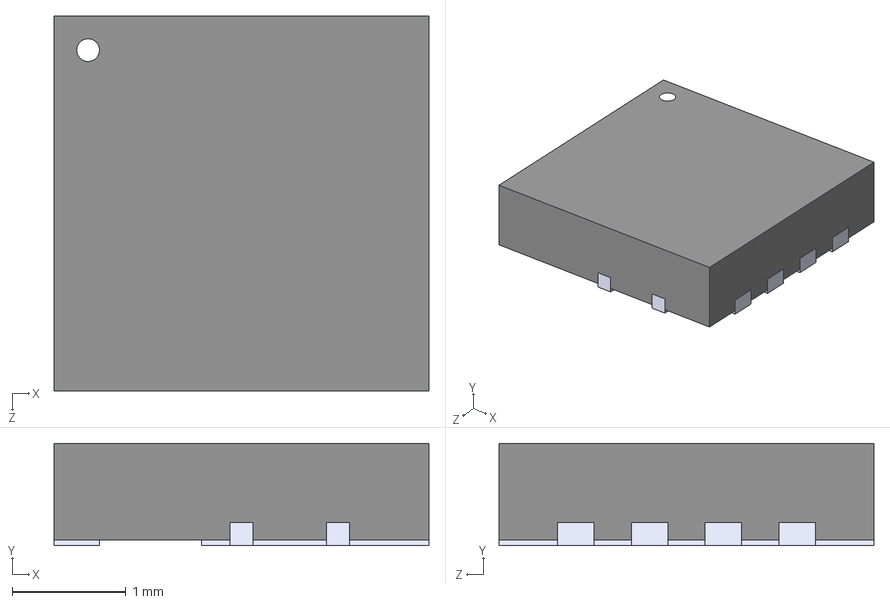
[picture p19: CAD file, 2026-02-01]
hardware/pcb-designs/common-libs/DMP3035SFG-7/3D/DMP3035SFG-7.stp
3.30 x 0.9 x 3.30 mm
DMN3024SFG-7
DMN3024SFG-7_6
DMN3024SFG-7_1
DMN3024SFG-7_5
DMN3024SFG-7_4
DMN3024SFG-7_3
DMN3024SFG-7_2

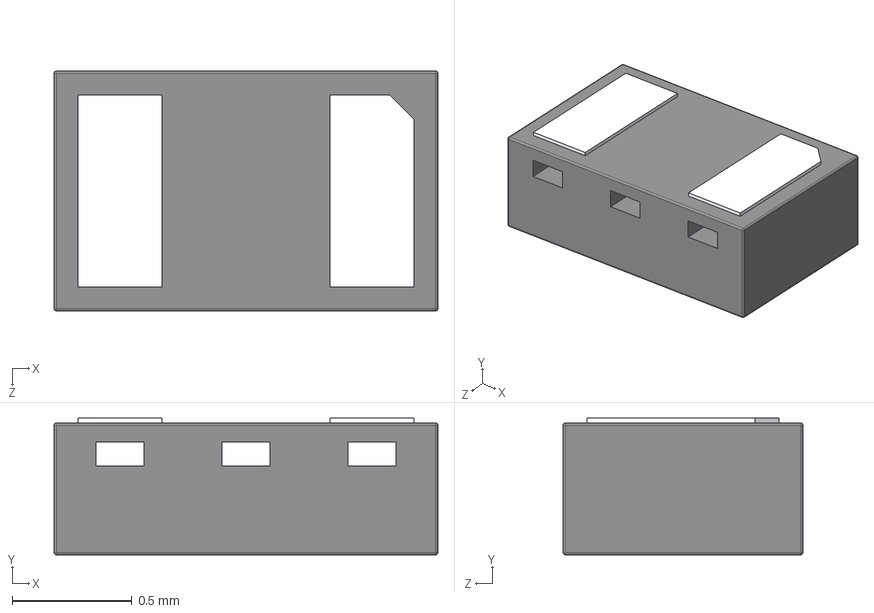
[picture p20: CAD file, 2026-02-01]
hardware/pcb-designs/common-libs/ESDA25P35-1U1M/3D/ESDA25P35-1U1M.stp
1.60 x 0.57 x 1.00 mm

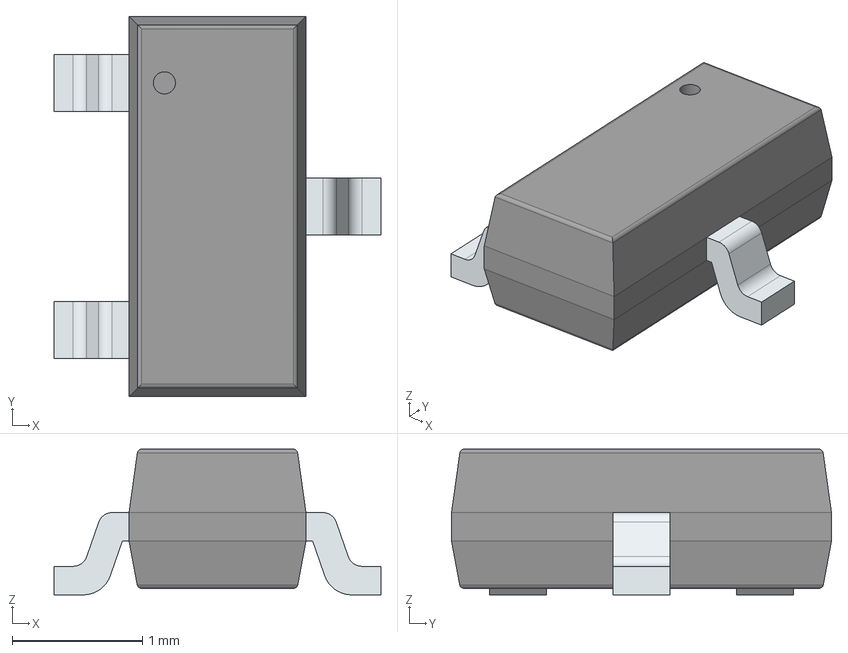
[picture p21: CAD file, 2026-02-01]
hardware/pcb-designs/common-libs/FDN358P/3D/FDN358P.stp
2.51 x 2.92 x 1.12 mm
PinsArrayL
FilletPinR

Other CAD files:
hardware/pcb-designs/common-libs/LM1084IS-ADJ_NOPB/3D/LM1084IS-ADJ_NOPB.stp
hardware/pcb-designs/common-libs/LM3480IM3-3.3_NOPB/3D/LM3480IM3-3.3_NOPB.stp
hardware/pcb-designs/common-libs/LM3480IM3X-3.3_NOPB/3D/LM3480IM3X-3.3_NOPB.stp
hardware/pcb-designs/common-libs/NCP1117STAT3G/3D/NCP1117STAT3G.stp
hardware/model3D/barrière/Bras_v1.stl
hardware/model3D/barrière/Bras_v1_1.stl
hardware/model3D/barrière/Support_Moteur_v1_1.stl
hardware/model3D/boitier-rfid/boitier-rfid.stl
hardware/pcb-designs/common-libs/2920L400_15MR/3D/2920L400_15MR.stp
hardware/pcb-designs/common-libs/74437356022/3D/74437356022.stp
hardware/pcb-designs/common-libs/74437356022/Allegro/indpm9785x300n.psm
hardware/pcb-designs/common-libs/74437356022/DEHDL/74437356022/chips/chips.prt
hardware/pcb-designs/common-libs/BQ296103DSGT/3D/BQ296103DSGT.stp
hardware/pcb-designs/common-libs/CSD17551Q3A/3D/CSD17551Q3A.stp
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

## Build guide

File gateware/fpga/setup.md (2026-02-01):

# Guide d'Installation et de Configuration

Ce document détaille les étapes techniques pour compiler le système d'exploitation (Buildroot), configurer le réseau pour MQTT et lancer l'application de contrôle de barrière sur le SoC LiteX/VexRiscv.

---

## 1. Génération du Système (Buildroot)

Nous devons générer une image Linux (Rootfs + Kernel) adaptée à l'architecture exacte du processeur VexRiscv configuré sur le FPGA.

### A. Configuration (`defconfig`)

Créez ou écrasez le fichier de configuration `configs/litex_vexriscv_defconfig` avec les paramètres suivants. Cette configuration active le support MQTT et ajuste le jeu d'instructions RISC-V.

```bash
cat > configs/litex_vexriscv_defconfig <<EOF
# --- ARCHITECTURE (STRICTE rv32ima) ---
BR2_riscv=y
BR2_RISCV_32=y

# Architecture manuelle pour correspondre au FPGA
BR2_RISCV_ISA_CUSTOM_RVI=y
BR2_RISCV_ISA_CUSTOM_RVM=y
BR2_RISCV_ISA_CUSTOM_RVA=y
# DÉSACTIVATION des extensions non supportées (Vital pour éviter SIGILL)
# BR2_RISCV_ISA_CUSTOM_RVC is not set
# BR2_RISCV_ISA_CUSTOM_RVF is not set
# BR2_RISCV_ISA_CUSTOM_RVD is not set

# ABI : On force les entiers (Soft Float)
BR2_RISCV_ABI_ILP32=y

# --- SYSTEME ---
BR2_TARGET_GENERIC_HOSTNAME="litex-c"
BR2_TARGET_GENERIC_ISSUE="Welcome to LiteX (C Version)"
BR2_SYSTEM_DHCP="eth0"
BR2_TARGET_ROOTFS_CPIO=y

# --- PAQUETS ---
# MQTT (Indispensable pour le projet)
BR2_PACKAGE_MOSQUITTO=y
BR2_PACKAGE_MOSQUITTO_BROKER=y
BR2_PACKAGE_MOSQUITTO_CLIENT=y

# Editeur de texte (Pratique pour débugger)
BR2_PACKAGE_NANO=y
EOF

```

### B. Compilation

Lancez la génération de l'image (cela peut prendre du temps la première fois) :

```bash
make litex_vexriscv_defconfig
make clean
make

```

> **⚠️ Note pour les utilisateurs WSL :**
> Si vous rencontrez l'erreur : `Your PATH contains spaces, TABs, and/or newline (\n) characters.`, vous devez nettoyer votre variable PATH avant de compiler :
> ```bash
> export PATH=/usr/local/sbin:/usr/local/bin:/usr/sbin:/usr/bin:/sbin:/bin
> 
> ```
> 
> 

---

## 2. Configuration Réseau (Windows / WSL)

Si votre Broker MQTT (Mosquitto) tourne sur votre PC de développement (Windows ou WSL) et que vous souhaitez que le FPGA s'y connecte via Ethernet, vous devez autoriser le trafic entrant.

Ouvrez un terminal (PowerShell ou CMD) en mode **Administrateur** et exécutez la commande suivante pour rediriger le port 1883 :

```powershell
netsh interface portproxy add v4tov4 listenaddress=0.0.0.0 listenport=1883 connectaddress=<IP_DE_VOTRE_PC> connectport=1883

```

*Remplacez `<IP_DE_VOTRE_PC>` par l'adresse IP de votre machine sur le réseau local.*

---

## 3. Déploiement de l'Application (v4)

Une fois le FPGA démarré sous Linux, transférez le fichier source `v4.c` (via SCP, carte SD, ou copier-coller avec `nano`).

### Compilation sur la cible

Utilisez `gcc` (fourni par Buildroot) pour compiler le programme en liant la bibliothèque Mosquitto :

```bash
gcc v4.c -o v4 -lmosquitto

```

### Utilisation

Le programme `v4` est un gestionnaire unifié. Vous devez spécifier quelles barrières activer et leur configuration initiale.

**Syntaxe :** `./v4 <ID> <ID:SENS> ...`

* `ID` : Numéro de la barrière (0 à 3).
* `SENS` (Optionnel) : `0` pour Normal, `1` pour Inversé.

**Exemples :**

1. **Activer les barrières 0 et 1 en mode normal :**
```bash
./v4 0 1

```

2. **Activer la barrière 0 en inversé et la 2 en normal :**
```bash
./v4 0:1 2:0

```

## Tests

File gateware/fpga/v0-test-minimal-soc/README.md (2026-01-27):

# SoC MicroBlaze + IP “barrière” (AXI) — Nexys A7

L’objectif était d’intégrer le pilotage de la barrière dans un SoC sur FPGA : **MicroBlaze** pour la supervision et la logique “haut niveau”, et un bloc matériel dédié pour les fonctions **temps-réel** (commande moteur, prise en compte capteurs, signaux d’indication). Cette approche permettait d’obtenir une implémentation plus **spécifique** et **optimisée** pour le besoin du projet.

---

## 1. Intérêt de l’approche SoC

- **Spécialisation de l’interface** : exposition de commandes/états strictement utiles (registres dédiés au pilotage).
- **Déterminisme** : exécution des actions critiques (timing, sécurité) au niveau matériel.
- **Modularité** : séparation claire entre décisions haut niveau (CPU) et exécution temps-réel (FPGA).
- **Évolutivité** : ajout de fonctionnalités côté logiciel sans modifier la logique matérielle de base, tant que l’interface AXI reste stable.

---

## 2. Fonctionnalités couvertes par le bloc “barrière” (niveau système)

Le bloc matériel regroupe les fonctions nécessaires au pilotage local de la barrière :

- Commande actionneur (ex. moteur pas à pas via sorties **4 phases**)
- Lecture d’un capteur de présence (proximité)
- Condition d’autorisation : activation moteur uniquement si **enable** ET **présence détectée**
- Sélection de vitesse (2 bits)
- Gestion du sens (direction) avec synchronisation
- Indicateurs : LED capteur, LED direction, buzzer (activité)

### Repères Nexys A7 (signaux)
- `clk` : 100 MHz  
- `reset` : bouton (actif haut)  
- `enable`, `direction`, `speed_sel[1:0]` : switches  
- `prox_sensor` : entrée capteur (1 = présence)  
- `phases[3:0]` : sorties driver (type ULN2003)  
- `buzzer_out` : buzzer  

---

## 3. Architecture du SoC (Vivado Block Design)

Le SoC est construit avec l’IP Integrator (Vivado) autour des éléments suivants :

- **MicroBlaze**
- **BRAM** + contrôleur (mémoire instructions/données)
- **AXI Interconnect**
- Périphériques AXI usuels (UARTLite, GPIO, Timer…)
- IP custom **`barrier_ctrl` (AXI4-Lite)** pour l’interface CPU ↔ bloc barrière

Principe d’échange :

1. Écriture de commandes via registres AXI-Lite (`CTRL`, `SPEED`, …)
2. Exécution matérielle temps-réel au niveau de l’IP
3. Lecture de l’état et des capteurs (`STATUS`, `SENSORS`, …)
4. Option : interruptions (IRQ) pour signaler des événements (timeout, anomalie, etc.)

---

## 4. IP `barrier_ctrl` : interface AXI-Lite (registre map)

Le choix a été de proposer une interface volontairement simple et dédiée au projet.

| Registre | Type | Description |
|---|---:|---|
| `CTRL` | W | activation / commande (start/stop) / options |
| `SPEED` | W | sélection vitesse (2 bits) |
| `STATUS` | R | état global (ready/running/fault + sens actif…) |
| `SENSORS` | R | image des capteurs (proximité, etc.) |
| `CFG` | R/W | paramètres (ex : inversion sens, options sécurité) |

Comportements clés (implémentés côté matériel) :
- Autorisation moteur conditionnée par `enable` **et** `prox_sensor`
- Synchronisation de la direction (robustesse vis-à-vis des entrées externes)
- Activation du buzzer lors de l’activité moteur

---

## 5. Mise en place Gateware (Vivado)

### A. Assemblage du Block Design
- Ajout MicroBlaze
- Ajout BRAM + controller
- Ajout AXI Interconnect
- Ajout UARTLite (console) et/ou GPIO si nécessaire
- Intégration de `barrier_ctrl` (AXI4-Lite)

### B. Points d’attention
- Propagation correcte des signaux clock/reset
- Attribution des adresses AXI (Address Editor)
- Connexion des ports externes (capteur, phases moteur, buzzer, LEDs)

### C. Contraintes (XDC) Nexys A7
- Horloge 100 MHz
- Bouton reset
- Switches de commande
- GPIO capteur
- Sorties phases + buzzer + LEDs

---

## 6. Génération du bitstream et export matériel (XSA)

Flux Vivado :

- Synthesis → Implementation → Generate Bitstream
- Export hardware (incluant le bitstream) → génération du `.xsa`

Le fichier `.xsa` sert de base à la création de la plateforme côté Vitis.

---

## 7. Côté logiciel (Vitis) : scénario minimal visé

Un programme baremetal de validation suffisait pour confirmer l’intégration :

- Initialisation UART
- Écriture `CTRL` et `SPEED`
- Lecture `STATUS` et `SENSORS` en boucle
- Option : gestion IRQ si activée

---

## 8. Évolution du projet

L’approche MicroBlaze était pertinente pour obtenir une solution **sur-mesure** et optimisée. Dans le contexte du projet, la suite n’a pas été poursuivie jusqu’à une intégration complète côté Vitis, et une autre orientation a été retenue pour la continuité.

---

## 9. Debug recommandé

- LEDs : indicateurs d’état (présence/direction/activité)
- UART : traces côté CPU
- ILA : observation des transactions AXI et des signaux internes de l’IP

---

## Annexes

### Checklist rapide (Vivado)
- Adresses AXI cohérentes (Address Editor)
- Clock/reset propagés correctement
- XDC complet (pins + IOSTANDARD)
- Export `.xsa` avec bitstream

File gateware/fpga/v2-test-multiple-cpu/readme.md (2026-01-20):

# Guide : Activer le Dual-Core (SMP) sur Linux-on-LiteX-VexRiscv

Ce document résume les modifications nécessaires pour faire tourner Linux sur un SoC LiteX avec 2 cœurs VexRiscv (SMP) sur une carte Nexys4DDR (adaptable aux autres cartes).

## 1. Génération du Matériel (Gateware)

Compiler le bitstream en spécifiant 2 CPUs. Cela modifie la carte mémoire et les adresses des périphériques.

```bash
./make.py --board=nexys4ddr --cpu-count=2 --build
```

> **Note :** Cette étape génère un fichier DTS de base dans `build/nexys4ddr/dts/nexys4ddr.dts`, mais il est souvent incomplet (manque le 2ème CPU).

## 2. Modification du Device Tree (DTS)

Le fichier `.dts` généré automatiquement ne déclare souvent que le CPU0. Il faut éditer manuellement `build/nexys4ddr/dts/nexys4ddr.dts`.

### A. Ajouter le CPU1

Dans la section `cpus { ... }`, copier le bloc `cpu@0` et le modifier pour créer `cpu@1`.
**Important :** Il faut définir un label unique pour le contrôleur d'interruption (ici `L1`).

```dts
        /* ... après la fermeture de cpu@0 ... */
        CPU1: cpu@1 {
            device_type = "cpu";
            compatible = "riscv";
            riscv,isa = "rv32i2p0_ma";
            riscv,isa-base = "rv32i";
            riscv,isa-extensions = "a", "i", "m";
            mmu-type = "riscv,sv32";
            reg = <1>;           /* ID du CPU */
            clock-frequency = <75000000>;
            status = "okay";
            
            /* ... caches et TLBs identiques au CPU0 ... */
            d-cache-size = <4096>; 
            /* ... etc ... */

            /* Label L1 pour le contrôleur d'interruption du CPU1 */
            L1: interrupt-controller {
                #address-cells = <0>;
                #interrupt-cells = <0x00000001>;
                interrupt-controller;
                compatible = "riscv,cpu-intc";
            };
        };

```

### B. Mettre à jour le CLINT (Timer & Soft IRQ)

Chercher le bloc `riscv,clint0` (souvent label `lintc0`) et ajouter les références au CPU1 (`&L1`).

```dts
        lintc0: clint@f0010000 {
            compatible = "riscv,clint0";
            /* Ajouter &L1 3 &L1 7 pour le second coeur */
            interrupts-extended = <&L0 3 &L0 7 &L1 3 &L1 7>;
            reg = <0xf0010000 0x10000>;
            reg-names = "control";
        };

```

### C. Mettre à jour le PLIC (Périphériques Externes)

Chercher le bloc `sifive,plic-1.0.0` (souvent label `intc0`) et ajouter les références au CPU1.

```dts
        intc0: interrupt-controller@f0c00000 {
            compatible = "sifive,fu540-c000-plic", "sifive,plic-1.0.0";
            /* Ajouter &L1 11 &L1 9 pour le second coeur (Machine/Supervisor external) */
            interrupts-extended = <&L0 11 &L0 9 &L1 11 &L1 9>;
            /* ... le reste ne change pas ... */
        };

```

## 3. Compilation du Device Tree (DTB)

Transformer le fichier source modifié (`.dts`) en binaire (`.dtb`) et le placer dans le dossier des images.

```bash
dtc -O dtb -o images/nexys4ddr.dtb build/nexys4ddr/dts/nexys4ddr.dts

```

## 4. Configuration du Boot (boot.json)

Vérifier dans le fichier `.dts` l'adresse définie par `linux,initrd-start`.
Exemple trouvé : `<0x41000000>`.

Modifier `images/boot.json` pour aligner l'adresse de chargement du `rootfs` avec celle attendue par le DTS.

```json
{
    "Image":         "0x40000000",
    "nexys4ddr.dtb": "0x40ef0000",
    "rootfs.cpio":   "0x41000000",  <-- Doit correspondre au linux,initrd-start du DTS
    "fw_jump.bin":   "0x40f00000"
}

```

## 5. Chargement et Test

Charger le système via le port série.

```bash
python3 make.py --board=nexys4ddr --load

```

Une fois logué dans Linux, vérifier la présence des deux cœurs :

```bash
cat /proc/cpuinfo

```

Le résultat doit afficher `processor : 0` et `processor : 1` tel que :
```bash
# cat /proc/cpuinfo
processor       : 0
hart            : 0
isa             : rv32i2p0_ma
mmu             : sv32

processor       : 1
hart            : 1
isa             : rv32i2p0_ma
mmu             : sv32
```

## 6. Flasher le nouveau firmware :

Vivado a généré un fichier .bit (utilisé pour charger le FPGA temporairement). Mais pour flasher la puce mémoire (SPI Flash) et rendre la configuration permanente, OpenOCD a besoin d'un fichier .bin.

Il faut donc convertir le .bit en .bin manuellement via Vivado.
Pour cela nous allons générer un script `gen_bin.tcl`: 

### 1. Création du script de conversion

```bash
cat <<EOF > gen_bin.tcl
write_cfgmem -force -format bin -interface SPIx1 -size 16 -loadbit "up 0x0 ./build/nexys4ddr/gateware/nexys4ddr.bit" -file ./build/nexys4ddr/gateware/nexys4ddr.bin
exit
EOF
```

> **Note :** Cette commande génère un script TCL pour Vivado. Elle utilise l'outil `write_cfgmem` pour transformer le bitstream FPGA (`.bit`) en une image mémoire brute (`.bin`) compréhensible par le programmateur de flash.
> * **`-interface SPIx1`** : Indispensable ici pour correspondre à la configuration par défaut du bitstream (Single SPI). Si on mettait `SPIx4` (Quad-SPI), Vivado rejetterait le fichier car le design n'a pas été explicitement compilé pour le mode x4.
> * **`-size 16`** : Spécifie la taille de la puce mémoire de la Nexys4DDR (16 Mo).
> * **`up 0x0`** : Place la configuration du FPGA au tout début de la mémoire Flash.
> 
> 

### 2. Exécution de Vivado

```bash
vivado -mode tcl -source gen_bin.tcl

```

> **Note :** Cette commande lance Vivado en mode "TCL" (Terminal/Ligne de commande), sans charger l'interface graphique lourde. Elle exécute immédiatement les instructions du fichier `gen_bin.tcl` créé précédemment. C'est la méthode standard pour automatiser des tâches Vivado dans un terminal Linux.

---

### 3. Flashage (Rappel)

```bash
python3 make.py --board=nexys4ddr --flash

```

> **Note :** Cette commande utilise OpenOCD pour écrire le fichier `.bin` généré dans la mémoire non-volatile (SPI Flash) de la carte. Au prochain redémarrage électrique, le FPGA chargera cette configuration automatiquement.
> **Attention :** Seul le Gateware (SoC + CPU) est flashé. Le noyau Linux et le système de fichiers (`rootfs`, `Image`, `dtb`) doivent être placés sur la carte SD pour un démarrage autonome.

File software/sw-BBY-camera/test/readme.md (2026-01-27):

# Environnement de Test & Simulation





## 📖 À quoi sert ce dossier ?

Ce dossier contient des outils pour vérifier que ton projet fonctionne correctement, que ce soit sur ton **PC (Simulation)** ou sur la **BeagleBone (Réel)**.

---

## 🚀 1. Simulation sur PC (Sans matériel)

Utilise ces scripts pour tester l'interface graphique et la logique sans avoir besoin des caméras ou des capteurs.

### A. Générer un historique fictif (`populate_db.py`)
Ce script est **indispensable pour la démo**. Il remplit la base de données avec 10 jours d'entrées/sorties réalistes pour que le Dashboard ne soit pas vide.

* **Crée les utilisateurs :** `admin` (Mdp: `admin123`) et `driver` (Mdp: `user123`).
* **Simule l'activité :** Génère des mouvements de véhicules et place certains véhicules en état "GARÉ" pour tester l'affichage temps réel.

**Commande :**
```bash
python3 populate_db.py
```
### B. Lancer le Site Web de Test (`test_server_render.py`)
Lance une version "Mock" du serveur. C'est exactement comme le `main.py`, mais les caméras sont remplacées par des images générées par ordinateur.

* **Utilité :** Travailler sur le HTML/CSS (`templates/`) sans lancer la reconnaissance d'image.
* **Accès :** Ouvre `http://192.168.78.2:5000/` dans ton navigateur.

**Commande :**
```bash
python3 test_server_render.py
```
### 🎨 Interfaces Web à Tester

Une fois le serveur lancé, tu peux tester les écrans suivants (situés dans `../templates/`) :

* **Connexion (`login.html`) :**
    * **Admin :** Login `admin` / Pass `admin123`
    * **User :** Login `driver` / Pass `user123`
* **Dashboard Conducteur (`dashboard.html`) :**
    * Accessible avec le compte `driver`.
    * Affiche l'état des véhicules (**Vert** = Garé / **Orange** = Sorti).
    * Affiche l'historique personnel sous forme de calendrier interactif.
* **Console Admin (`index.html`) :**
    * Accessible avec le compte `admin`.
    * Affiche les flux vidéo simulés et les logs MQTT en temps réel.

---

## 🛠 2. Tests Matériels (Sur BeagleBone)

Lance ces scripts directement sur la carte pour valider les composants physiques individuellement.

| Fichier | Matériel testé | Description |
| :--- | :--- | :--- |
| `test_lcd_manager.py` | Écran LCD | Affiche "TEST" fixe puis fait défiler "BRAVO". |
| `test_sensor_manager.py` | Capteur BME680 | Lit et affiche la température/humidité dans la console. |
| `test_camera_manager.py` | Webcam & IA | Lance un flux vidéo avec détection de plaques (carrés verts). |
| `test_db_manager.py` | SQLite | Teste la création, lecture et suppression d'un utilisateur. |

**Exemple d'utilisation :**

```bash
# Pour tester l'écran LCD
python3 test_lcd_manager.py

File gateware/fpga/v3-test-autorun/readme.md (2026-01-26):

---

# Mise en place de l'Autorun (SD Card)

Configuration du Linux pour qu'il exécute automatiquement un script modifiable (`startup.sh`) situé sur la carte SD au démarrage.

**Avantage :** Cette méthode permet de modifier la configuration réseau ou les programmes à lancer **sans jamais avoir à recompiler le noyau ou le rootfs**. Il suffit d'éditer un fichier texte sur la carte SD depuis un PC ou même de le transférer depuis **le réseau** !

---

## Architecture

1. **Côté Système (Interne/Fixe) :** Un script "Pont" (`S99autorun`) est intégré dans l'image `rootfs.cpio`. Il se lance à la fin du boot, monte la carte SD et cherche le script utilisateur.
2. **Côté Utilisateur (Externe/Modifiable) :** Un script `startup.sh` est placé à la racine de la carte SD. Il contient vos commandes (IP, lancement d'app, etc.).

---

## Partie 1 : Installation du "Pont" (À faire une seule fois)

Cette étape modifie l'image du système de fichiers pour qu'elle sache lire la carte SD au démarrage.

### 1. Créer le script d'initialisation

Sur votre PC de développement, allez dans le dossier cible de Buildroot :

```bash
cd buildroot/output/target/etc/init.d/
```

Créez le fichier **`S99autorun`** :

```bash
nano S99autorun
```

Copiez-y le contenu suivant :

```bash
#!/bin/sh
# /etc/init.d/S99autorun
# Script de pont : Monte la SD et lance startup.sh s'il existe.

SD_MOUNT_POINT="/mnt/sd"
SD_DEVICE="/dev/mmcblk0p1"
USER_SCRIPT="startup.sh"

echo "[Autorun] Checking for SD Card..."

# 1. Créer le dossier de montage
mkdir -p $SD_MOUNT_POINT

# 2. Monter la partition FAT32 de la SD
mount $SD_DEVICE $SD_MOUNT_POINT

# 3. Vérifier et exécuter le script utilisateur
if [ -f "$SD_MOUNT_POINT/$USER_SCRIPT" ]; then
    echo "[Autorun] Found $USER_SCRIPT, executing..."
    
    # Force les droits d'exécution (utile si système de fichiers FAT)
    chmod +x "$SD_MOUNT_POINT/$USER_SCRIPT"
    
    # Exécution du script
    /bin/sh "$SD_MOUNT_POINT/$USER_SCRIPT"
else
    echo "[Autorun] No $USER_SCRIPT found on SD card."
fi
```

### 2. Rendre le script exécutable

C'est indispensable pour que Linux le lance au boot :

```bash
chmod +x S99autorun
```

### 3. Recompiler le Rootfs

Revenez à la racine du dossier `buildroot` et régénérez l'image :

```bash
cd ../../../..  # Retour racine buildroot
make
```

Le nouveau fichier **`rootfs.cpio`** (situé dans `output/images/`) contient maintenant le pont. Copiez-le sur votre carte SD.

---

## Partie 2 : Utilisation (Script modifiable)

Cette étape se fait directement sur la carte SD. Vous pouvez modifier ce fichier à volonté depuis Windows ou Linux.

### 1. Créer le script utilisateur

À la racine de la carte SD, créez un fichier nommé **`startup.sh`**.

### 2. Exemple de contenu

Voici un template pour configurer l'Ethernet et lancer un binaire `v3`.

```bash
#!/bin/sh

echo "--------------------------------"
echo "   Démarrage Script Utilisateur "
echo "--------------------------------"

# --- Configuration Réseau ---
echo "Configuration de l'IP..."
ifconfig eth0 192.168.1.50 netmask 255.255.255.0 up

# Optionnel : Ping pour vérifier
# ping -c 1 192.168.1.100

# --- Lancement de l'Application ---
APP_PATH="/mnt/sd/v3"

if [ -f "$APP_PATH" ]; then
    echo "Lancement de l'application v3..."
    chmod +x "$APP_PATH"
    "$APP_PATH"
else
    echo "ERREUR : Le programme v3 est introuvable sur la SD !"
fi

echo "--------------------------------"
echo "   Fin du Script Utilisateur    "
echo "--------------------------------"
```

---

## Dépannage

* **Le script ne se lance pas ?**
* Vérifiez que le fichier sur la SD s'appelle bien `startup.sh` (attention aux extensions masquées sous Windows, type `startup.sh.txt`).
* Vérifiez que vous avez bien copié le **nouveau** `rootfs.cpio` sur la carte SD.

* **Erreur "Permission denied" ?**
* Le script `S99autorun` inclut une commande `chmod +x` automatique, mais assurez-vous que votre binaire (`v3`) est bien compilé pour l'architecture RISC-V.

* **Erreur de montage SD ?**
* Assurez-vous que la carte SD est formatée en **FAT32** et que c'est la première partition (`mmcblk0p1`).

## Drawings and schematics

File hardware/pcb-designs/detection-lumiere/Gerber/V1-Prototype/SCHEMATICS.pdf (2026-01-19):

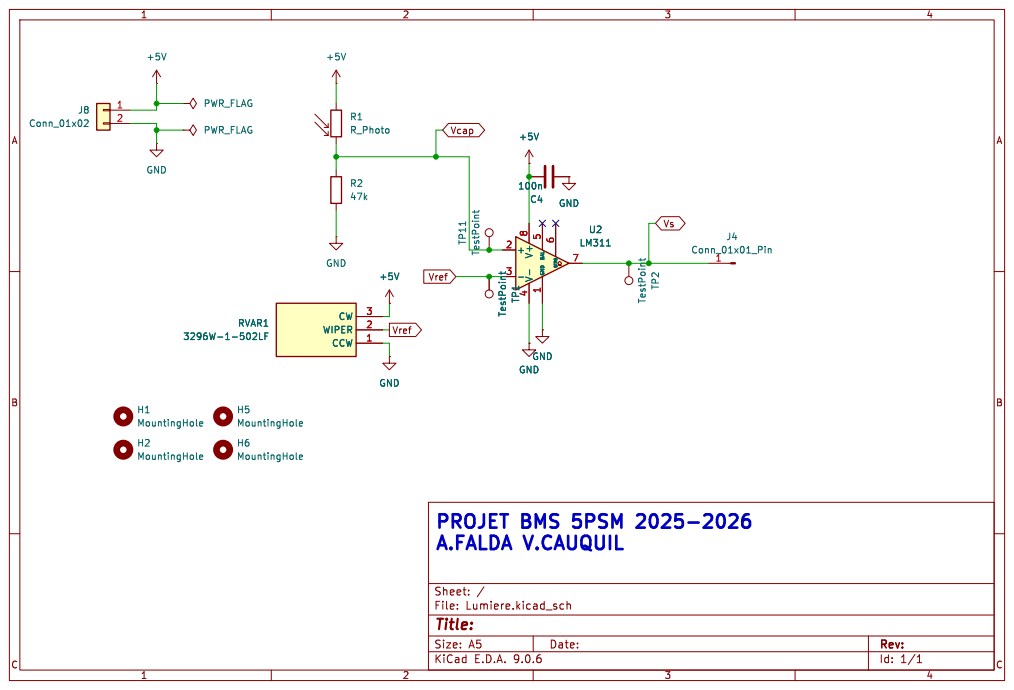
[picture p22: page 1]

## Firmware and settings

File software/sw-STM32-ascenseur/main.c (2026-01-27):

/**
 * @file main.c
 * @brief Firmware de contrôle d'ascenseur avec recalibrage automatique
 * @author A.Clerville
 * @date 2026-01-27
 * @details Gère un moteur pas-à-pas via un driver TMC5160 en SPI.
 * Inclut la gestion de trois étages, une rampe d'accélération logicielle,
 * un capteur de distance VL53L0X pour le recalage et une sécurité anti-collision.
 */

/* =========================================================================
 * INCLUDES
 * ========================================================================= */
#include <zephyr/kernel.h>
#include <zephyr/drivers/gpio.h>
#include <zephyr/drivers/spi.h>
#include <zephyr/sys/printk.h>
#include <zephyr/drivers/sensor.h>
#include <stdlib.h>

/* =========================================================================
 * MACROS & CONFIGURATION
 * ========================================================================= */

/* --- Configuration Étages (mm) --- */
#define HEIGHT_FLOOR_0    0
#define HEIGHT_FLOOR_1    170  
#define HEIGHT_FLOOR_2    336  
#define TOLERANCE_MM      10   

/* --- Réglages Moteur --- */
#define STEPS_PER_MM      350   
#define MAX_SPEED_US      200   
#define MIN_SPEED_US      1200  
#define RAMP_STEPS        2000  

/* --- Sens Moteur --- */
#define DIR_UP            0  
#define DIR_DOWN          1

/* --- Registres TMC5160 --- */
#define REG_GCONF         0x00
#define REG_GSTAT         0x01
#define REG_GLOBAL_SCALER 0x0B
#define REG_IHOLD_IRUN    0x10
#define REG_CHOPCONF      0x6C
#define REG_DRV_STATUS    0x6F

/* =========================================================================
 * MATÉRIEL (Devicetree)
 * ========================================================================= */

#define SPI_OP  (SPI_WORD_SET(8) | SPI_TRANSFER_MSB | SPI_MODE_CPOL | SPI_MODE_CPHA)
const struct spi_dt_spec tmc_spi = SPI_DT_SPEC_GET(DT_NODELABEL(tmc_spi), SPI_OP, 0);

static const struct gpio_dt_spec motor_en   = GPIO_DT_SPEC_GET(DT_ALIAS(motor_enable), gpios);
static const struct gpio_dt_spec motor_dir  = GPIO_DT_SPEC_GET(DT_ALIAS(motor_dir), gpios);
static const struct gpio_dt_spec motor_step = GPIO_DT_SPEC_GET(DT_ALIAS(motor_step), gpios);

/* Boutons */
static const struct gpio_dt_spec btn_stop   = GPIO_DT_SPEC_GET(DT_ALIAS(sw0), gpios);
static const struct gpio_dt_spec btn_f0     = GPIO_DT_SPEC_GET(DT_ALIAS(floor_btn_0), gpios);
static const struct gpio_dt_spec btn_f1     = GPIO_DT_SPEC_GET(DT_ALIAS(floor_btn_1), gpios);
static const struct gpio_dt_spec btn_f2     = GPIO_DT_SPEC_GET(DT_ALIAS(floor_btn_2), gpios);

/* Capteur */
const struct device *const distance_sensor = DEVICE_DT_GET_ANY(st_vl53l0x);

/* =========================================================================
 * FONCTIONS DRIVER TMC5160
 * ========================================================================= */

void tmc_write(uint8_t addr, uint32_t data) {
    uint8_t tx_buf[5];
    tx_buf[0] = addr | 0x80; 
    tx_buf[1] = (data >> 24) & 0xFF;
    tx_buf[2] = (data >> 16) & 0xFF;
    tx_buf[3] = (data >> 8) & 0xFF;
    tx_buf[4] = data & 0xFF;
    struct spi_buf tx = { .buf = tx_buf, .len = 5 };
    struct spi_buf_set tx_set = { .buffers = &tx, .count = 1 };
    spi_write_dt(&tmc_spi, &tx_set);
}

uint32_t tmc_read(uint8_t addr, uint8_t *status_byte) {
    uint8_t tx_buf[5] = { addr, 0, 0, 0, 0 };
    uint8_t rx_buf[5] = { 0 };
    struct spi_buf tx = { .buf = tx_buf, .len = 5 };
    struct spi_buf_set tx_set = { .buffers = &tx, .count = 1 };
    struct spi_buf rx = { .buf = rx_buf, .len = 5 };
    struct spi_buf_set rx_set = { .buffers = &rx, .count = 1 };
    spi_transceive_dt(&tmc_spi, &tx_set, &rx_set);
    if (status_byte) *status_byte = rx_buf[0];
    return (rx_buf[1] << 24) | (rx_buf[2] << 16) | (rx_buf[3] << 8) | rx_buf[4];
}

void configure_tmc_driver(void) {
    tmc_write(REG_GSTAT, 0x00000007);
    tmc_write(REG_GLOBAL_SCALER, 128);
    tmc_write(REG_CHOPCONF, 0x14410153); 
    tmc_write(REG_IHOLD_IRUN, 0x0002100A); 
}

/* =========================================================================
 * LOGIQUE ASCENSEUR
 * ========================================================================= */

bool is_floor_btn_pressed(const struct gpio_dt_spec *btn) {
    if (gpio_pin_get_dt(btn) == 0) { 
        k_sleep(K_MSEC(50)); 
        if (gpio_pin_get_dt(btn) == 0) return true;
    }
    return false;
}

int get_step_delay(int current_step, int total_steps) {
    int delay = MAX_SPEED_US; 
    if (current_step < RAMP_STEPS) {
        delay = MIN_SPEED_US - ((MIN_SPEED_US - MAX_SPEED_US) * current_step / RAMP_STEPS);
    }
    else if (current_step > (total_steps - RAMP_STEPS)) {
        int steps_left = total_steps - current_step;
        delay = MIN_SPEED_US - ((MIN_SPEED_US - MAX_SPEED_US) * steps_left / RAMP_STEPS);
    }
    return delay;
}

/* =========================================================================
 * MAIN
 * ========================================================================= */

int main(void)
{
    printk("\n=== ASCENSEUR : RECALIBRAGE AUTO ===\n");
    k_sleep(K_MSEC(100));

    /* Configuration GPIO */
    gpio_pin_configure_dt(&motor_en, GPIO_OUTPUT_INACTIVE);
    gpio_pin_configure_dt(&motor_dir, GPIO_OUTPUT_LOW);
    gpio_pin_configure_dt(&motor_step, GPIO_OUTPUT_LOW);

    gpio_pin_configure_dt(&btn_stop, GPIO_INPUT);
    gpio_pin_configure_dt(&btn_f0, GPIO_INPUT);
    gpio_pin_configure_dt(&btn_f1, GPIO_INPUT);
    gpio_pin_configure_dt(&btn_f2, GPIO_INPUT);

    /* Setup Driver */
    configure_tmc_driver();
    gpio_pin_set_dt(&motor_en, 1); 
    
    int64_t last_check = k_uptime_get();
    int current_mm = 999; 

    /* === SEQUENCE DE CALIBRAGE (INIT) === */
    printk("-> INITIALISATION...\n");
    gpio_pin_set_dt(&motor_dir, DIR_DOWN); 
    
    while (1) {
        if (gpio_pin_get_dt(&btn_stop) == 1) {
            printk("-> Sol (Bouton). OK.\n");
            gpio_pin_set_dt(&motor_dir, DIR_UP);
            for(int k=0; k<2000; k++) { 
                gpio_pin_set_dt(&motor_step, 1); k_busy_wait(10);
                gpio_pin_set_dt(&motor_step, 0); k_busy_wait(500); 
            }
            break;
        }
        gpio_pin_set_dt(&motor_step, 1); k_busy_wait(10);
        gpio_pin_set_dt(&motor_step, 0); k_busy_wait(300); 
    }
    current_mm = 0; 
    printk("-> PRET.\n");
    
    int target_mm = -1; 
    int next_target_mm = -1; 

    while (1) {
        
        // 1. LECTURE BOUTONS
        int requested_floor = -1;
        if (is_floor_btn_pressed(&btn_f0)) requested_floor = HEIGHT_FLOOR_0;
        else if (is_floor_btn_pressed(&btn_f1)) requested_floor = HEIGHT_FLOOR_1;
        else if (is_floor_btn_pressed(&btn_f2)) requested_floor = HEIGHT_FLOOR_2;

        if (requested_floor != -1) {
            if (target_mm == -1) {
                target_mm = requested_floor;
                printk("-> DEPART: %d mm\n", target_mm);
            }
            else if (target_mm != requested_floor && next_target_mm == -1) {
                next_target_mm = requested_floor;
                printk("-> MEMOIRE: %d mm\n", next_target_mm);
            }
        }

        // 2. MOUVEMENT INTELLIGENT
        if (target_mm != -1) {
            int dist_mm = target_mm - current_mm;
            
            if (abs(dist_mm) < TOLERANCE_MM) {
                 printk("-> Deja sur place.\n");
                 target_mm = -1;
            } 
            else {
                int total_steps = abs(dist_mm) * STEPS_PER_MM;
                printk("-> Trajet: %d mm (%d pas)\n", dist_mm, total_steps);

                if (dist_mm > 0) gpio_pin_set_dt(&motor_dir, DIR_UP);
                else gpio_pin_set_dt(&motor_dir, DIR_DOWN);

                for(int i = 0; i < total_steps; i++) {
                    int dynamic_delay = get_step_delay(i, total_steps);

                    gpio_pin_set_dt(&motor_step, 1);
                    k_busy_wait(10);
                    gpio_pin_set_dt(&motor_step, 0);
                    k_busy_wait(dynamic_delay); 

                    // --- STOP & RECALIBRAGE ---
                    if (gpio_pin_get_dt(&btn_stop) == 1) {
                        if (dist_mm < 0) {
                            printk("-> SOL TOUCHE : Recalibrage Auto !\n");
                            gpio_pin_set_dt(&motor_dir, DIR_UP);
                            for(int k=0; k<3500; k++) {
                                gpio_pin_set_dt(&motor_step, 1); k_busy_wait(10);
                                gpio_pin_set_dt(&motor_step, 0); k_busy_wait(500);
                            }
                            current_mm = 0; 
                            target_mm = -1; 
                            break; 
                        } 
                        else {
                            printk("!!! STOP URGENCE (Montee) !!!\n");
                            target_mm = -1;
                            break;
                        }
                    }
                }
            }

            if (target_mm == -1) {
                next_target_mm = -1; 
            } else {
                current_mm = target_mm;
                printk("-> ARRIVÉ THEORIQUE (%d mm).\n", current_mm);
                
                if (device_is_ready(distance_sensor)) {
                    struct sensor_value value;
                    if (sensor_sample_fetch(distance_sensor) == 0) {
                        sensor_channel_get(distance_sensor, SENSOR_CHAN_DISTANCE, &value);
                        int real_mm = (value.val1 * 1000) + (value.val2 / 1000);
                        if (abs(real_mm - current_mm) < 50) current_mm = real_mm;
                    }
                }

                k_sleep(K_MSEC(500)); 

                if (next_target_mm != -1) {
                    printk("-> ENCHAINEMENT: %d mm\n", next_target_mm);
                    target_mm = next_target_mm; 
                    next_target_mm = -1;        
                } else {
                    target_mm = -1; 
                    printk("-> En attente.\n");
                }
            }
        } 
        else {
            k_sleep(K_MSEC(10));
        }

        // 3. RESILIENCE
        if (k_uptime_get() - last_check > 2000) {
            last_check = k_uptime_get();
            uint8_t status = 0;
            tmc_read(REG_DRV_STATUS, &status);
            if ((status & 0x01) || (status & 0x02)) {
                configure_tmc_driver(); 
                gpio_pin_set_dt(&motor_en, 1);
            }
        }
    }
    return 0;
}

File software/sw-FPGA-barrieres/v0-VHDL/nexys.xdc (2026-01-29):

## Horloge 100 MHz
set_property -dict { PACKAGE_PIN E3 IOSTANDARD LVCMOS33 } [get_ports { clk }];
create_clock -add -name sys_clk_pin -period 10.00 -waveform {0 5} [get_ports { clk }];

## Bouton reset
set_property -dict { PACKAGE_PIN N17 IOSTANDARD LVCMOS33 } [get_ports { reset }];

## Interrupteurs
set_property -dict { PACKAGE_PIN J15 IOSTANDARD LVCMOS33 } [get_ports { enable }];    # SW0
set_property -dict { PACKAGE_PIN L16 IOSTANDARD LVCMOS33 } [get_ports { direction }]; # SW1
set_property -dict { PACKAGE_PIN M13 IOSTANDARD LVCMOS33 } [get_ports { speed_sel[0] }]; # SW2
set_property -dict { PACKAGE_PIN R15 IOSTANDARD LVCMOS33 } [get_ports { speed_sel[1] }]; # SW3

## Capteur de proximité
set_property -dict { PACKAGE_PIN D14 IOSTANDARD LVCMOS33 } [get_ports { prox_sensor }]; # JB1

## LEDs
set_property -dict { PACKAGE_PIN H17 IOSTANDARD LVCMOS33 } [get_ports { led_sensor }];  # LED0
set_property -dict { PACKAGE_PIN K15 IOSTANDARD LVCMOS33 } [get_ports { led_dir }];     # LED1

## Buzzer (sortie 3.3V quand moteur ON)
set_property -dict { PACKAGE_PIN F3 IOSTANDARD LVCMOS33 } [get_ports { buzzer_out }];   # JD10 (ou autre pin libre)

## Phases du moteur (vers ULN2003)
set_property -dict { PACKAGE_PIN C17 IOSTANDARD LVCMOS33 } [get_ports { phases[0] }];
set_property -dict { PACKAGE_PIN D18 IOSTANDARD LVCMOS33 } [get_ports { phases[1] }];
set_property -dict { PACKAGE_PIN E18 IOSTANDARD LVCMOS33 } [get_ports { phases[2] }];
set_property -dict { PACKAGE_PIN G17 IOSTANDARD LVCMOS33 } [get_ports { phases[3] }];

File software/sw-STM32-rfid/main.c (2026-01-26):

/**
 * @file main.c
 * @brief Firmware de gestion d'accès Parking (STM32 Node)
 * @author A.Falda
 * @version 1.0.4 (Integration Camera + RFID)
 * @date 2026-01-25
 * * @details Ce module gère l'interface LVGL, la lecture RFID via SPI,
 * les capteurs GPIO et la communication MQTT sur Zephyr OS.
 * Inclut la logique de sécurité Anti-Tailgating.
 */

/* =========================================================================
 * INCLUDES
 * ========================================================================= */
#include <zephyr/device.h>
#include <zephyr/devicetree.h>
#include <zephyr/drivers/display.h>
#include <zephyr/drivers/gpio.h>
#include <zephyr/drivers/spi.h>
#include <zephyr/kernel.h>
#include <zephyr/logging/log.h>
#include <zephyr/sys/printk.h>
#include <zephyr/sys/util.h>
#include <zephyr/net/net_ip.h>
#include <zephyr/net/socket.h>
#include <zephyr/net/mqtt.h>
#include <zephyr/random/random.h>
#include <lvgl.h>
#include <stdio.h>
#include <string.h>
#include <ctype.h>
#include <stdbool.h>
#include <errno.h>

LOG_MODULE_REGISTER(app, LOG_LEVEL_INF);

/* =========================================================================
 * MACROS & CONFIGURATION
 * ========================================================================= */

/* --- Compatibilité LVGL (Version Agnostic) --- */
#if defined(LVGL_VERSION_MAJOR) && (LVGL_VERSION_MAJOR >= 8)
  #define LVGL_SCREEN_ACT()       lv_scr_act()
  #define LVGL_DISP_DEFAULT()     lv_disp_get_default()
  #define LVGL_TIMER_HANDLER()    lv_timer_handler()
  #define LVGL_PASS_BULLET(ta)    lv_textarea_set_password_bullet((ta), "*")
  #define BTNMX_CREATE            lv_btnmatrix_create
  #define BTNMX_SET_MAP           lv_btnmatrix_set_map
  #define BTNMX_GET_SELECTED(o)   lv_btnmatrix_get_selected_btn(o)
  #define BTNMX_GET_TEXT(o,i)     lv_btnmatrix_get_btn_text((o),(i))
  #define BTNMX_BTN_NONE          LV_BTNMATRIX_BTN_NONE
  #define OBJ_HIDE(o)             lv_obj_add_flag((o), LV_OBJ_FLAG_HIDDEN)
  #define OBJ_SHOW(o)             lv_obj_clear_flag((o), LV_OBJ_FLAG_HIDDEN)
#else
  #define LVGL_SCREEN_ACT         lv_scr_act
  #define LVGL_DISP_DEFAULT       lv_disp_get_default
  #define LVGL_TIMER_HANDLER      lv_task_handler
  #define LVGL_PASS_BULLET(ta)    lv_textarea_set_password_bullet((ta), '*')
  #define BTNMX_CREATE            lv_btnmatrix_create
  #define BTNMX_SET_MAP           lv_btnmatrix_set_map
  #define BTNMX_GET_SELECTED(o)   lv_btnmatrix_get_active_btn(o)
  #define BTNMX_GET_TEXT(o,i)     lv_btnmatrix_get_btn_text((o),(i))
  #define BTNMX_BTN_NONE          LV_BTNMATRIX_BTN_NONE
  #define OBJ_HIDE(o)             lv_obj_set_hidden((o), true)
  #define OBJ_SHOW(o)             lv_obj_set_hidden((o), false)
#endif

/* --- Paramètres Application --- */
#define IT_SECRET_CODE      "2580"
#define MAX_CODE_LEN        4
#define DELAY_BEFORE_CLOSE  5000 
#define DELAY_BEFORE_OFF    2000
#define ADMIN_BADGE_UID     "AA63F605"

/* --- Configuration MQTT --- */
#define MQTT_SERVER_ADDR    "192.168.78.2"
#define MQTT_SERVER_PORT    1883
#define MQTT_TOPIC_BADGE    "RFID/ID"
#define MQTT_TOPIC_CMD      "RFID/CMD"
#define MQTT_TOPIC_BEAGLEY  "parking/barrier_0/state" /* Topic Unifié */
#define MQTT_TOPIC_ADD      "RFID/ADD"
#define MQTT_TOPIC_DEL      "RFID/DEL"
#define MQTT_TOPIC_PRES     "RFID/PRESENCE"
#define MQTT_TOPIC_BARRIER_IN "parking/barrier_0/state" 

/* --- Configuration SPI / RFID --- */
#define SPI_BUS      DT_NODELABEL(spi2)
#define GPIOA_NODE   DT_NODELABEL(gpioa)
#define CS_PIN       8  
#define RST_PIN      15 

/* =========================================================================
 * GLOBALS & HANDLERS
 * ========================================================================= */

/* Périphériques Hardware */
static const struct device *disp_dev; 
static struct gpio_dt_spec barrier_gpio = GPIO_DT_SPEC_GET_OR(DT_ALIAS(barrier), gpios, (struct gpio_dt_spec){0});
static const struct gpio_dt_spec capteur_lum = GPIO_DT_SPEC_GET(DT_ALIAS(capteur_lumiere), gpios);
static const struct gpio_dt_spec relais_led = GPIO_DT_SPEC_GET(DT_ALIAS(led_eclairage), gpios);
static const struct gpio_dt_spec capteur_voiture = GPIO_DT_SPEC_GET(DT_ALIAS(capteur_voiture), gpios);
static const struct gpio_dt_spec backlight_gpio = GPIO_DT_SPEC_GET(DT_ALIAS(backlight), gpios);

/* SPI Hardware */
static const struct device *spi_dev;
static const struct device *gpioa_dev;
static const struct spi_config spi_cfg = { 
    .frequency = 4000000, 
    .operation = SPI_WORD_SET(8) | SPI_TRANSFER_MSB, 
    .slave = 0 
};

/* Contextes Réseau */
static uint8_t mqtt_rx_buf[256];
static uint8_t mqtt_tx_buf[256];
static struct mqtt_client mqtt_client_ctx;
static struct sockaddr_storage mqtt_broker;
static bool mqtt_connected = false;

/* Flags d'état (Volatile pour accès inter-thread/ISR) */
static volatile bool cmd_unlock = false;
static volatile bool cmd_deny = false;
static volatile bool cmd_added = false;
static volatile bool cmd_deleted = false;
static volatile bool cmd_error_db = false;
static volatile bool cmd_it_debug_on = false;
static volatile bool cmd_it_debug_off = false;
static volatile bool cmd_badge_valid_only = false; 

/* Objets UI LVGL */
static lv_obj_t *page_home, *page_debug;
static lv_obj_t *status_home, *status_debug;
static lv_obj_t *barrier_home, *barrier_debug;
static lv_obj_t *ta_code, *btnm_keypad, *log_ta;

/* Variables d'état Application */
static lv_timer_t *relock_timer  = NULL; 
static bool debug_action_mode    = false; 
static int  admin_mode_state     = 0;
static int  ui_lock_timer        = 0; 
static int  last_car_state       = -1;
static bool screen_is_active     = false;
static bool barrier_unlocked     = false;
static bool mode_it_actif        = false; 

/* Buffers RFID */
static volatile bool rfid_badge_ok_request = false;
static volatile bool rfid_error_request    = false;
static char last_rfid_log[160];
static char last_badge_uid[16] = {0};
static char log_last1[160] = {0};
static char log_last2[160] = {0};

/* =========================================================================
 * HELPERS & LOGGING
 * ========================================================================= */

/**
 * @brief Ajoute une ligne au log affiché sur l'écran tactile (FIFO 2 lignes).
 */
static void log_push(const char *line) {
    strncpy(log_last2, log_last1, sizeof(log_last2)-1);
    strncpy(log_last1, line, sizeof(log_last1)-1);
    if (log_ta) {
        char buf[340];
        snprintf(buf, sizeof(buf), "%s\n%s", log_last2, log_last1);
        lv_textarea_set_text(log_ta, buf);
    }
}

static void ui_set_status_all(const char *txt, lv_color_t color) {
    if (status_home) { 
        lv_label_set_text(status_home, txt); 
        lv_obj_set_style_text_color(status_home, color, 0); 
    }
    if (status_debug && !debug_action_mode) { 
        lv_label_set_text(status_debug, txt); 
        lv_obj_set_style_text_color(status_debug, color, 0); 
    }
}
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

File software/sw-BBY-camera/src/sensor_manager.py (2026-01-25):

import time
import random

# ==========================================
# GESTION SIMULATION (WINDOWS vs LINUX)
# ==========================================
try:
    import spidev
    from adafruit_bme680 import Adafruit_BME680_SPI
    IS_REAL_HARDWARE = True
except ImportError:
    IS_REAL_HARDWARE = False
    # On mock spidev pour que les classes techniques ne plantent pas à la définition
    class MockSpi:
        def open(self, bus, device): pass
        def max_speed_hz(self, speed): pass
        def mode(self, mode): pass
        def xfer2(self, data): return [0]*len(data)
        def close(self): pass
    spidev = type('obj', (object,), {'SpiDev': MockSpi})
    
    # On crée une fausse classe BME680 pour éviter les NameError
    class Adafruit_BME680_SPI: pass

# ==========================================
# 1. CLASSES TECHNIQUES (Smart-SPI)
# ==========================================
class Smart_SPI_Adapter:
    def __init__(self, cs_pin):
        self.spi = spidev.SpiDev()
        self.spi.open(0, cs_pin)
        
        # Réglages pour stabilité maximale
        self.spi.max_speed_hz = 50000 
        self.spi.mode = 3 
        
        self.pending_write = None 

    def try_lock(self): return True
    def unlock(self): pass
    def configure(self, baudrate=100000, polarity=0, phase=0, bits=8): pass

    def write(self, buf, start=0, end=None):
        if end is None: end = len(buf)
        self.pending_write = list(buf[start:end])

    def readinto(self, buf, start=0, end=None, write_value=0):
        if end is None: end = len(buf)
        length = end - start
        
        tx_buffer = []
        if self.pending_write:
            tx_buffer.extend(self.pending_write)
            self.pending_write = None
        
        tx_buffer.extend([write_value] * length)
        rx_buffer = self.spi.xfer2(tx_buffer)
        
        response = rx_buffer[-length:]
        for i in range(length):
            buf[start + i] = response[i]

class FakeCS:
    def __init__(self, adapter): 
        self.adapter = adapter
    def switch_to_output(self, value=True): pass
    def switch_to_input(self): pass
    @property
    def value(self): return True
    @value.setter
    def value(self, val):
        if val and self.adapter.pending_write:
            self.adapter.spi.xfer2(self.adapter.pending_write)
            self.adapter.pending_write = None

# ==========================================
# 2. MANAGER PRINCIPAL
# ==========================================
class SensorManager:
    def __init__(self, cs_pin=1):
        self.cs_pin = cs_pin
        self.sensor = None
        self.adapter = None
        self.offset = -5 
        self.init_sensor()

    def init_sensor(self):
        # --- MODE SIMULATION ---
        if not IS_REAL_HARDWARE:
            print("[SENSOR] ℹ️ Mode Simulation activé (Valeurs aléatoires)")
            self.sensor = "MOCK_SENSOR" # Juste pour dire qu'il est "là"
            return
        # -----------------------

        print(f"[SENSOR] Init Smart-SPI (Mode 3) sur CS{self.cs_pin}...")
        try:
            self.adapter = Smart_SPI_Adapter(self.cs_pin)
            cs_fake = FakeCS(self.adapter)
            self.sensor = Adafruit_BME680_SPI(self.adapter, cs_fake)
            self.sensor.sea_level_pressure = 1013.25
            
            print("[SENSOR] Préchauffage pour éliminer les valeurs 193°C...")
            for i in range(3):
                try:
                    _ = self.sensor.temperature
                    time.sleep(0.5) 
                except:
                    pass

            print("[SENSOR] ✅ OK (Prêt)")
        except Exception as e:
            print(f"[SENSOR] ❌ Erreur: {e}")
            self.sensor = None

    def get_temperature(self):
        # --- SIMULATION ---
        if not IS_REAL_HARDWARE:
            return round(random.uniform(19.0, 24.0), 1)
        # ------------------

        if not self.sensor: return None
        try:
            temp = self.sensor.temperature + self.offset
            if temp > 100 or temp < -50:
                return None
            return round(temp, 1)
        except: return None

    def get_humidity(self):
        # --- SIMULATION ---
        if not IS_REAL_HARDWARE:
            return round(random.uniform(40.0, 60.0), 1)
        # ------------------

        if not self.sensor: return None
        try:
            return round(self.sensor.humidity, 1)
        except: return None

    def close(self):
        if IS_REAL_HARDWARE and self.adapter and hasattr(self.adapter, 'spi'):
            self.adapter.spi.close()

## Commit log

2026-01-19 new file: "hardware/model3D/barri\303\250re/Bras_v1.stl" new file: "hardware/model3D/barri\303\250re/Bras_v1_1.stl" new file: "hardware/model3D/barri\303\250re/Support_Moteur_v1_1.stl" new file: "har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
    [Bras_v1.stl, Bras_v1_1.stl, Support plateforme.stl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]
2026-01-30 Refine PCB design documentation and add camera link
    Updated PCB design documentation to enhance clarity and technical coherence. Added a link for the Sony IMX415 camera and removed unnecessary content.
2026-01-30 Rename rd.md to readme.md in pcb-designs
2026-01-30 Enhance readme with I/O interfaces details for BMS
    Added detailed descriptions of I/O interfaces and functionalities for the BMS, including communication, user interface, output control, and thermal management.
2026-01-30 Add load estimation CSV for BMS calculations
    Added load estimation data for components and usage scenarios.
    [load_estimation.csv]
2026-01-30 Add pack_4S3P_energy.csv with battery specifications
    [pack_4S3P_energy.csv]
2026-01-30 Add technical references for BMS and USB-PD design
    This document contains technical references, datasheets, application notes, and reference schematics used for the BMS and USB-PD design.
2026-02-01 Upload BMS files and Adapateur 24pin to 22pin design
    [1054500101.step, 1571563-6.stp, 2920L400_15MR.stp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]
2026-02-02 Revise directory structure for PCB designs
    Updated directory structure to include new PCB designs and additional resources for BMS and light detection.
2026-02-02 Revise directory structure in BMS README
    Updated directory structure and file references in the README.
2026-02-02 Add reference to Battery management ICs
